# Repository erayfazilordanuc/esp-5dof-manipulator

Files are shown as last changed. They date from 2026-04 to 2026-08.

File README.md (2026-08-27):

# ESP32 5-DOF Manipulator

<p align="center">
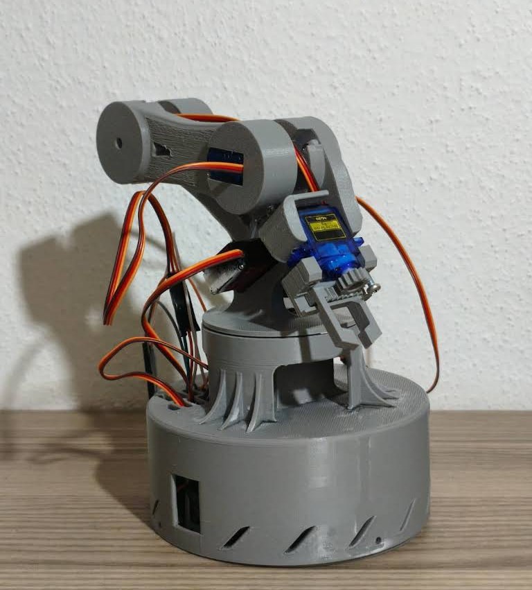
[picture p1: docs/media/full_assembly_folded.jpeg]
Arm in the folded pose
  
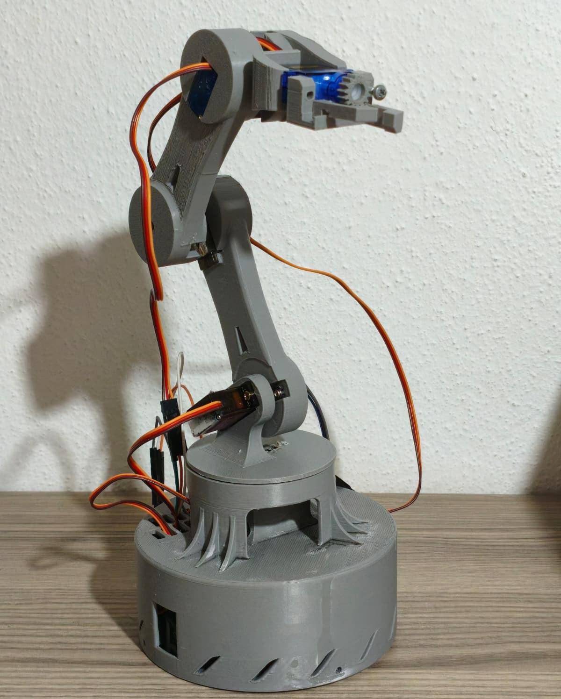
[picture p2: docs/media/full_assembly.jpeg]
Arm reaching forward
  
</p>

A five-axis robotic arm built from scratch: a 3D-printed structure, an ESP32 running the
motion controller, and a control page served straight off the board over Wi-Fi. No host
computer involved. The firmware is called ArmPilot.

The arm is driven by servos that report nothing back — no encoder, no current sense, no way
to ask one where it is. Three problems follow, and most of the design answers one of them:

- A servo that has just been powered up slams to whatever pulse width reaches it first, so
  firmware that attaches and writes an angle in the same breath makes the arm jump on boot.
- Software PWM on a chip that is also servicing Wi-Fi interrupts jitters — audible as
  buzzing, visible as twitching.
- Commanding a servo straight to its target makes it accelerate as hard as it can, which on
  a printed arm means wobble on departure and overshoot on arrival.

This is an open-loop system. The firmware controls what it *commands*; whether a link ended
up where it was told is not something the board can observe.

## Mechanics

<p align="center">
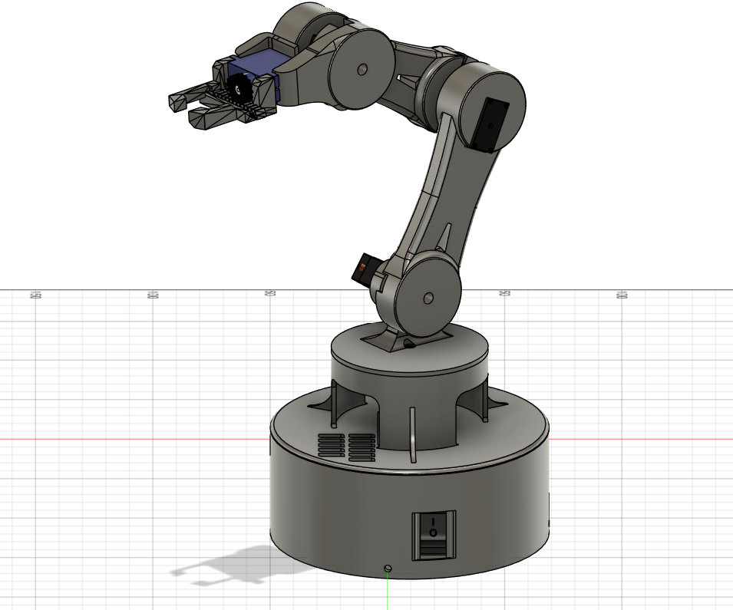
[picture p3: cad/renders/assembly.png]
CAD assembly
  
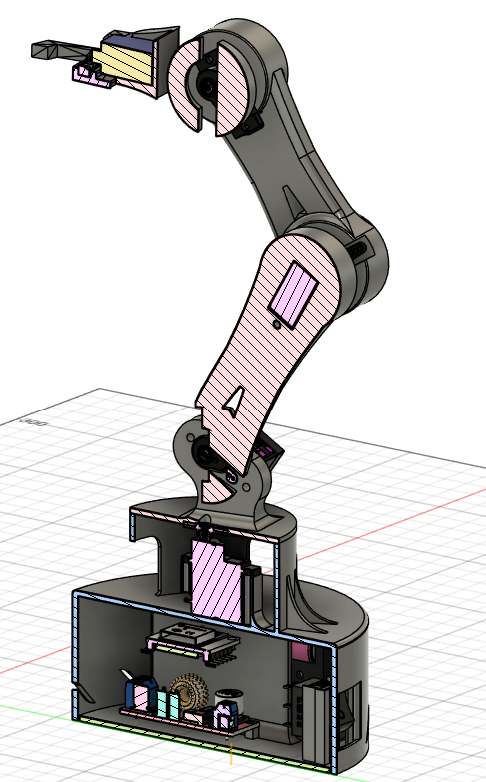
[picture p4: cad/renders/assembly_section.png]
Section view
  
</p>

Structural parts are printed in PETG rather than PLA, for less flex under load and better
tolerance of the heat that builds up around servos in a sealed base. The section view was the
working drawing for servo clearance, cable routing and wall thickness. The base is a closed
cylinder holding the electronics and battery, keeping the heaviest parts at the bottom and
the arm planted when the elbow is fully extended.

STLs are in [`cad/print_files/`](cad/print_files/), Fusion 360 sources in
[`cad/source/`](cad/source/). The browser draws the arm from link lengths the board sends on
connect, so changing the mechanics means editing one struct: base radius 62 mm, floor to
shoulder 105 mm, shoulder to elbow 110 mm, elbow to wrist 95 mm, wrist to tip 72 mm.

## Electronics

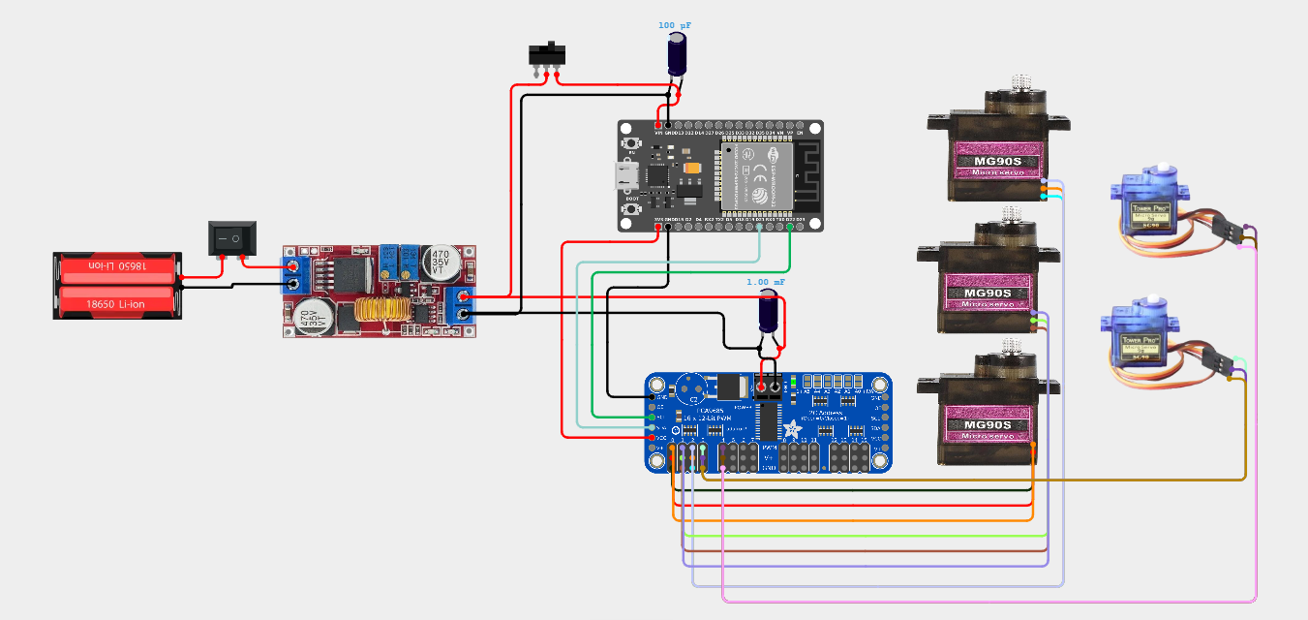
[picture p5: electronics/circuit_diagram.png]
Circuit diagram


All five PWM channels come from a PCA9685 at I²C `0x40` rather than the ESP32 itself. It
generates the pulses in hardware at 50 Hz while the ESP32 only writes a pulse width over the
bus at 400 kHz, so whatever the CPU is busy with never reaches the servo signal.

Two 18650 cells in series feed a single XL4015 buck converter, which supplies the ESP32 and
the servo rail in parallel — 100 µF on the logic side, 1000 µF across the servo rail. It is
still one rail, so a hard stall can drag the logic down with it. Splitting them is the next
revision: [`circuit_diagram_v2.png`](electronics/circuit_diagram_v2.png) gives the servos a
dedicated 8 A XL4016E1, and
[`circuit_diagram_v2_with_bms.png`](electronics/circuit_diagram_v2_with_bms.png) adds a 2S BMS
and USB-C charging.

| Qty | Part | Notes |
|---|---|---|
| 1 | ESP32-WROOM-32 devkit, 30-pin | Wi-Fi and two cores |
| 1 | Adafruit PCA9685 | 16-channel 12-bit PWM, I²C `0x40` |
| 3 | MG90S servo | Base, shoulder, elbow |
| 2 | SG90 servo | Wrist and gripper |
| 1 | XL4015 buck converter | Shared 5 V rail |
| 2 | 18650 Li-ion and holder | In series, about 7.4 V nominal |
| 1 each | 100 µF / 1000 µF electrolytic | Logic side / servo rail |
| 2 | Rocker / slide switch | Master and logic cut-off |

`GPIO21`/`GPIO22` carry I²C, `3V3` feeds the PCA9685 logic, grounds are common. Any 50 Hz
servo works in place of these; trim each axis with `usMin`/`usMax` in the joint table.

<p align="center">
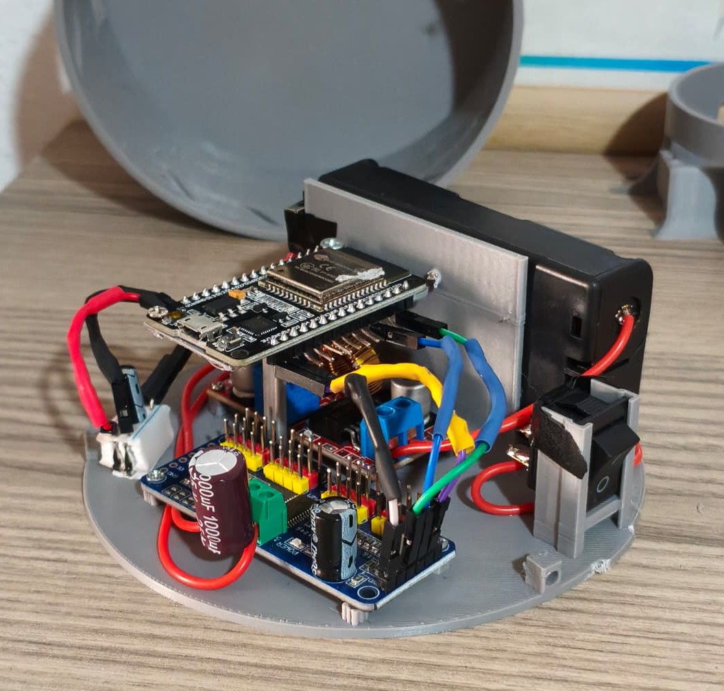
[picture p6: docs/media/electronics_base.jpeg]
Electronics stack in the base
  
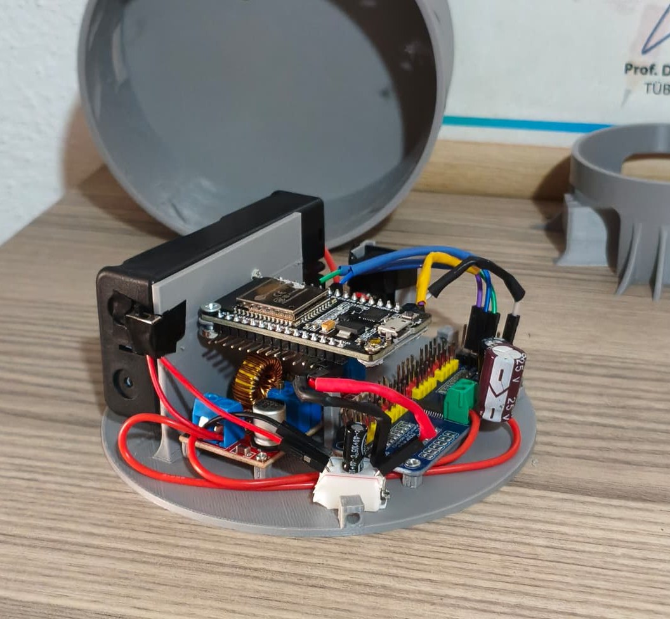
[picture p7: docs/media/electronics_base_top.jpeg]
Top view of the base
  
</p>

## Motion control

Without position feedback a PID loop has nothing to close around, so instead of correcting
error after the fact ArmPilot never commands a move the arm cannot follow. Every axis owns a
profile generator ([`motion_axis.h`](firmware/include/motion_axis.h)) stepped at 100 Hz,
handing the servo an intermediate setpoint every 10 ms under velocity, acceleration and jerk
limits.

```
velocity
   ^      ______________
   |     /              \     jerk limit smooths the take-off
   |    /                \    v = sqrt(2*a*distance) brake curve
   +---/------------------\--> time
```

The asymmetry is the point: jerk is limited only while accelerating, while braking keeps full
acceleration authority. Velocity is capped at `sqrt(2*a*distance)` from the target, so the
commanded setpoint arrives and stops rather than sailing past — a property of the generator,
not a correction applied afterwards. What the physical link then does is unobservable, and
none of this compensates for disturbance or a stalled servo.

Profile stepping runs in its own FreeRTOS task, pinned to core 1 at priority 3 with a fixed
period. Telemetry and WebSocket work happen in the lower-priority Arduino loop, so a busy
network is what gets preempted — the control step runs on time and the web work waits.

**[docs/motion-control.md](docs/motion-control.md)** — per-axis limits, profile output for a
90° move, the `s`/`s²`/`s³` speed-scaling law, task layout.

## The control page

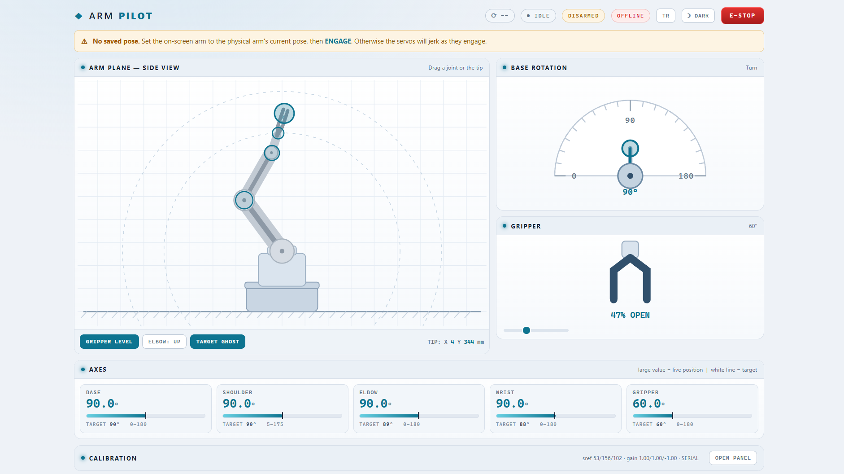
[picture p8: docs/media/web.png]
ArmPilot control page


The UI is a single page held in flash as `PROGMEM`, so there is no filesystem image to build
or upload. It gives two 2D views instead of five sliders, because sliders make you think in
servo angles and the shape of the robot is what you care about: a side view where dragging
the end point solves shoulder and elbow together through inverse kinematics, and a top view
dial for base rotation.

The solid arm is the setpoint the profile generator is commanding, streamed at 20 Hz; the
dashed ghost is the target it is working toward, fading as the two converge. Both come from
the firmware's model rather than from the arm itself, so the gap between them is how much of
the commanded move is still outstanding, not a tracking error. `Space` is emergency stop and
resume, `H` is home, `P` is park. English and Turkish come from one dictionary and the theme
follows the OS until overridden; both choices stay in `localStorage`, which is why the boot
reason arrives from the board as a code (`BROWNOUT`, `PANIC`, …) and is put into words in the
browser.

**Calibration** lives in the same page. Splined horns mount at whatever tooth lines up during
assembly, so each joint carries a linear map — `joint = wRef + gain * (servo - sRef)` —
instead of an assumed zero, and the sign of `gain` carries direction, so the reversed wrist
mount is just −1. Two unknowns need two samples: engage, pose the arm, drag the on-screen arm
to match, save two clearly different poses. The firmware fits and stores them, and rejects
fits it cannot trust, because a bad fit turns into motion. See
**[docs/calibration.md](docs/calibration.md)**.

Commands go over a WebSocket at `/ws` as plain text:

```
a <a0> <a1> <a2> <a3> <a4>   set all axes
j <id> <deg>                 set one axis
s <scale>                    speed scale, 0.15 to 1.30
c engage|release|home|park|stop|resume|save
k ...                        calibration: sample, solve, flip direction, reset
```

The board answers with a `hello` frame (geometry, joint limits, IP, last reset code), a `cal`
frame whenever calibration changes, and a 20 Hz state packet.

## Starting up without the jump

At boot ArmPilot emits no pulses at all: `ArmController::begin()` puts every PCA9685 channel
into full-off, so the servos stay torque-free and the arm cannot move until asked.

Two seconds after motion settles the joint angles go to NVS. On the next boot they are read
back as the assumed pose, and pressing engage writes that *stored* angle to each channel in
turn, 220 ms apart: the commanded angle already matches the physical one so nothing moves,
and staggering keeps the inrush from pulling the supply down. With no stored pose — or if the
arm was moved by hand while off — the page says so and asks you to match the on-screen arm to
the real one first.

What this cannot fix: if the ESP32 resets, outputs shut off and the arm drops under its own
weight. The servos have no brake. Wiring `/OE` to a GPIO lets the firmware kill outputs in
hardware too, but it does not hold the arm up.

## Build and flash

You need [PlatformIO](https://platformio.org/); dependencies resolve from `platformio.ini`.

```bash
git clone https://github.com/erayfazilordanuc/esp-5dof-manipulator.git
cd esp-5dof-manipulator/firmware

# Wi-Fi credentials are not kept in version control
cp include/secrets_example.h include/secrets.h   # then fill in SSID and password

pio run              # build
pio run -t upload    # flash
pio device monitor   # the IP address is printed here
```

If the network is unreachable the board brings up its own access point, `ArmPilot-AP` /
`armpilot1`, at `http://192.168.4.1`; on your own network `http://armpilot.local` works over
mDNS. The servos come up free by design — press engage in the UI to energise them.

`python tools/preview.py` extracts the embedded page and serves it on `localhost`, so UI work
does not need a flash cycle. Tuning is split between `firmware/include/config.h` (AP fallback,
I²C pins, control rate, boot behaviour) and `firmware/src/config.cpp` (joint table, link
geometry, calibration defaults); both are pushed to the browser on connect.

## When the servos go limp

Almost always the ESP32 has reset: outputs shut off, torque disappears, the arm sags. The
cause is captured on boot and reported as `BROWNOUT`, `PANIC` or `WATCHDOG`, and the page
also watches uptime — if it runs backwards while you are connected, the board restarted under
you and the badge says so. Brownout is the usual answer on a shared rail: give the servos
their own 5–6 V supply, tie the grounds together, keep 1000 µF across the rail.
`ENGAGE_STAGGER_MS` spreads out the start-up current, but peak current during a move is a
question of what the supply can deliver.

## Repository layout

```
cad/          print_files/ (STLs + v1 archive), renders/, source/ (Fusion 360)
docs/         motion-control.md, calibration.md, media/
electronics/  Circuit diagrams, plus legacy/ for the v1 schematic
firmware/     include/, src/, tools/preview.py, legacy/ (excluded from the build)
```

## What's next

Closing the loop is the gap worth naming: an IMU on the forearm, or angles pulled from
high-frame-rate video, would make the pose the arm actually reaches measurable and turn the
profile numbers from commanded into observed. Past that, this firmware is meant to become the
low-level hardware interface for an autonomous setup — micro-ROS bridging the board to a host,
a URDF model to simulate against, and MoveIt 2 planning off-board.

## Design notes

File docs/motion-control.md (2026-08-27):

# Motion control

Detail behind the [motion control section](../README.md#motion-control) of the main README.
Implementation: [`motion_axis.h`](../firmware/include/motion_axis.h), limits in
[`config.cpp`](../firmware/src/config.cpp).

## Why a profile generator and not a PID

A PID loop needs a measurement to subtract from the setpoint. The servos give none, so
there is nothing to close a loop around. The alternative is to make the reference itself
followable: shape every command into a curve that stays inside limits the mechanism is known
to handle, and hand the servo an intermediate setpoint every 10 ms rather than a distant
target.

This is not equivalent to feedback control. It removes the failure modes that come from
commanding steps into an inertial system, and it does nothing about disturbance, load or a
servo that stalls. Those stay invisible to the firmware.

## The curve

```
velocity
   ^      ______________
   |     /              \     jerk limit smooths the take-off
   |    /                \    v = sqrt(2*a*distance) brake curve
   +---/------------------\--> time
```

Each 10 ms step, per axis:

1. Compute the highest velocity from which the axis could still stop within the remaining
   distance: `vBrake = sqrt(2 * aMax * |error|)`.
2. Command `min(vMax, vBrake)`, signed toward the target.
3. Take the acceleration that reaches it, clamped to `±aMax`.
4. Rate-limit that acceleration by `jMax * dt` **only while speeding up**. While braking,
   full acceleration authority is available immediately.
5. Integrate.

Step 4 is the asymmetry that matters. Jerk limiting on departure is what stops a printed arm
wobbling as it leaves; jerk limiting on arrival would delay the brake and let the axis run
long. Because velocity is capped by the brake curve at every step, the commanded position
converges on the target instead of passing it — a property of the generator, not a
correction applied afterwards.

Retargeting mid-move keeps the current velocity and re-solves from there, so a new command
during motion blends rather than restarting from zero.

## Profile output for a 90° move

At the default 0.85x speed scale:

| Axis | Duration | Peak velocity | Travelled in first 100 ms |
|---|---|---|---|
| Base | 3.52 s | 34 °/s | 2 % |
| Shoulder | 4.39 s | 25 °/s | 2 % |
| Elbow | 2.27 s | 60 °/s | 3 % |
| Wrist | 1.82 s | 81 °/s | 4 % |
| Gripper | 1.41 s | 111 °/s | 5 % |

These describe the setpoint stream the servos are handed, not the motion of the physical
link. With nothing reporting back from the arm, only the first is observable. The small
figures in the last column are the jerk limit working: the axis eases off the mark rather
than snapping.

## Per-axis limits

| Axis | Channel | Range | Home | Park | v max | a max | jerk max |
|---|---|---|---|---|---|---|---|
| Base | 0 | 0–180° | 90° | 90° | 40 °/s | 55 °/s² | 300 °/s³ |
| Shoulder | 1 | 5–175° | 90° | 125° | 30 °/s | 42 °/s² | 220 °/s³ |
| Elbow | 2 | 0–180° | 90° | 155° | 70 °/s | 110 °/s² | 700 °/s³ |
| Wrist | 3 | 0–180° | 90° | 120° | 95 °/s | 160 °/s² | 1000 °/s³ |
| Gripper | 4 | 0–180° | 60° | 60° | 130 °/s | 260 °/s² | 1800 °/s³ |

Base and shoulder are slowest on purpose: they carry the most inertia and the most load.

## Speed scaling

The UI slider spans 0.15x to 1.30x and scales the whole set together:

```
vMax * s        aMax * s²       jMax * s³
```

Those exponents keep the shape of the curve invariant — a slow move is the same move
stretched in time, not a differently shaped one. Scaling only velocity would produce a move
that still departs abruptly and merely crawls in the middle.

## Task structure

Profile generation runs in its own FreeRTOS task, created with:

```c
xTaskCreatePinnedToCore(motionTask, "motion", 6144, nullptr, 3, nullptr, 1);
```

Priority 3 puts it above the Arduino `loopTask` (priority 1), which is where telemetry
broadcast and WebSocket housekeeping live. So when the network is busy, the scheduler
preempts the web work and runs the control step on time — not the other way round. A control
loop whose period depends on network load is not a control loop.

Two things make the timing forgiving beyond that. The task sleeps to a fixed period rather
than a fixed delay, so its own work does not accumulate drift. And servo pulses come from the
PCA9685, which keeps emitting clean 50 Hz output on its own — a late task writes a slightly
stale pulse width, it does not produce a malformed pulse.

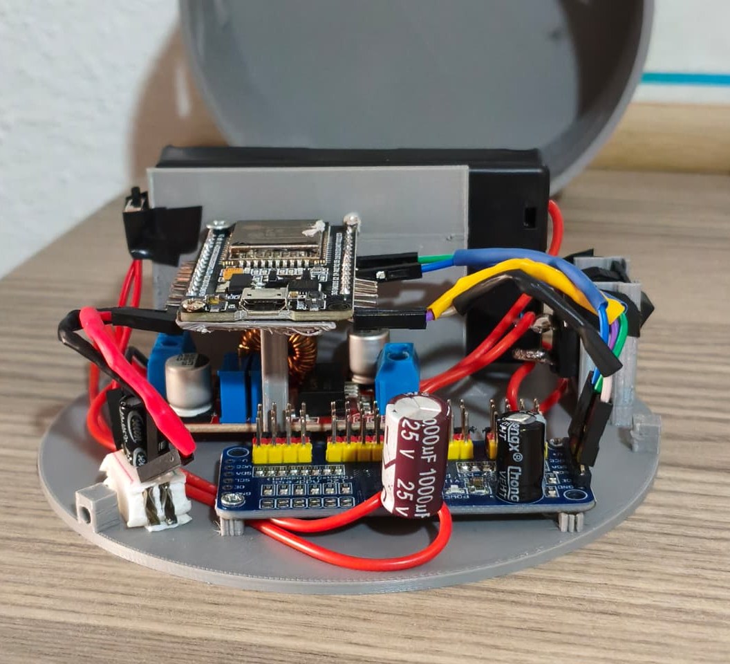
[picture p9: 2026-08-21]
docs/media/electronics_base_front.jpeg

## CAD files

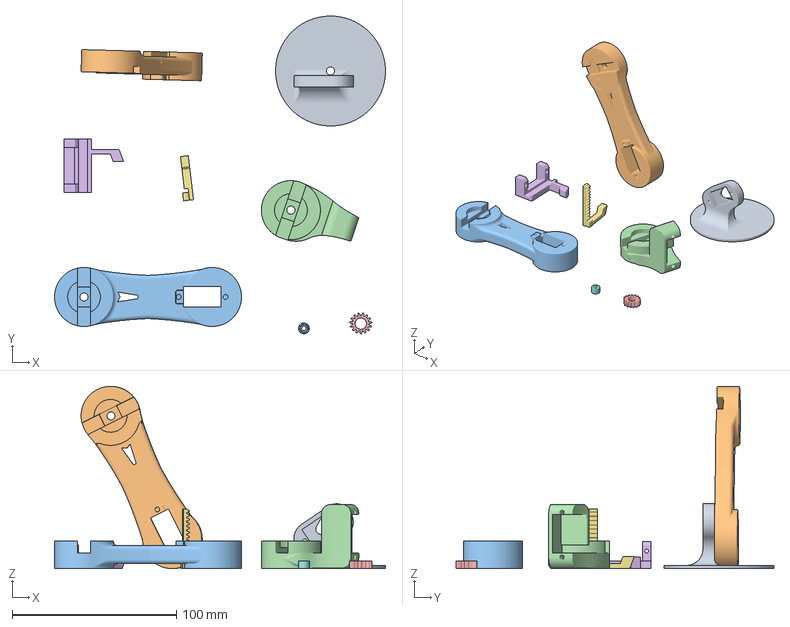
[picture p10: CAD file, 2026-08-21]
cad/print_files/after the base prints.3mf
201.7 x 193.8 x 111.1 mm
J1 Lid.stl
J2 Arm.stl
J3 Arm.stl
J4 wHousing.stl
Gripper Round Gear.stl
Gripper Mount.stl
Gripper Gear and Finger.stl
Servo Shoulder Center.stl

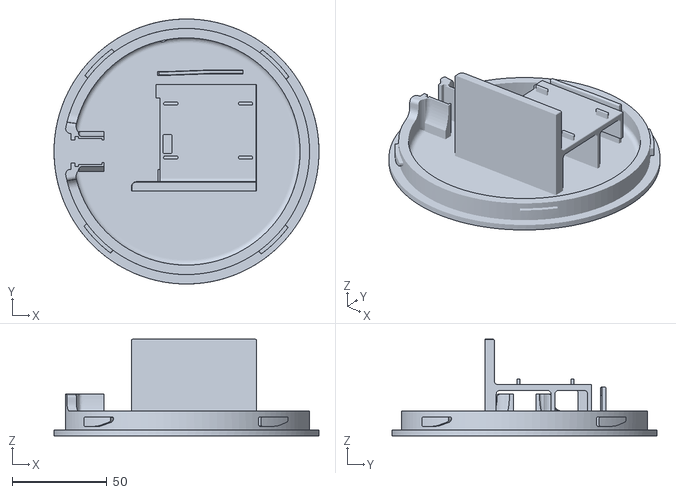
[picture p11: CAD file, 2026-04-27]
cad/print_files/v1/Base Housing.stl
140.0 x 140.0 x 51.0

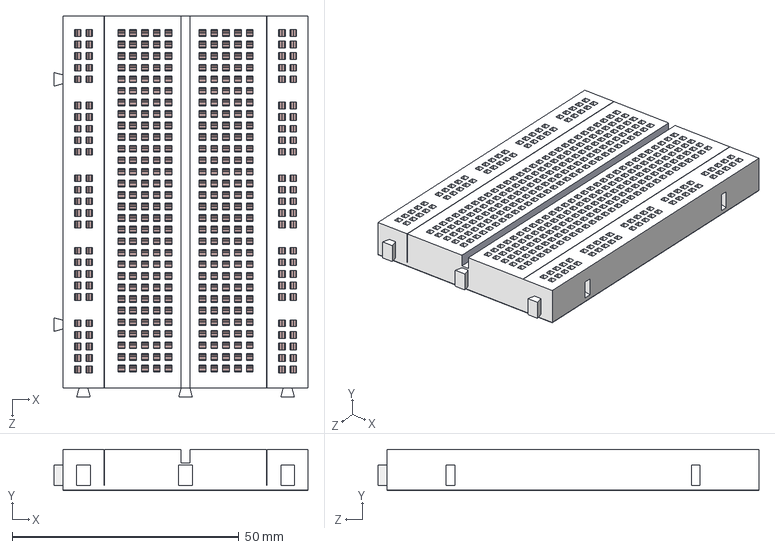
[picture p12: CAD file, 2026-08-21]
cad/source/Imports/8-5-x-5-5-1.snapshot.1/Макетная плата 8,5 x 5,5 см/Макетная плата 8,5 x 5,5 см.STEP
56.0 x 9.10 x 84.0 mm

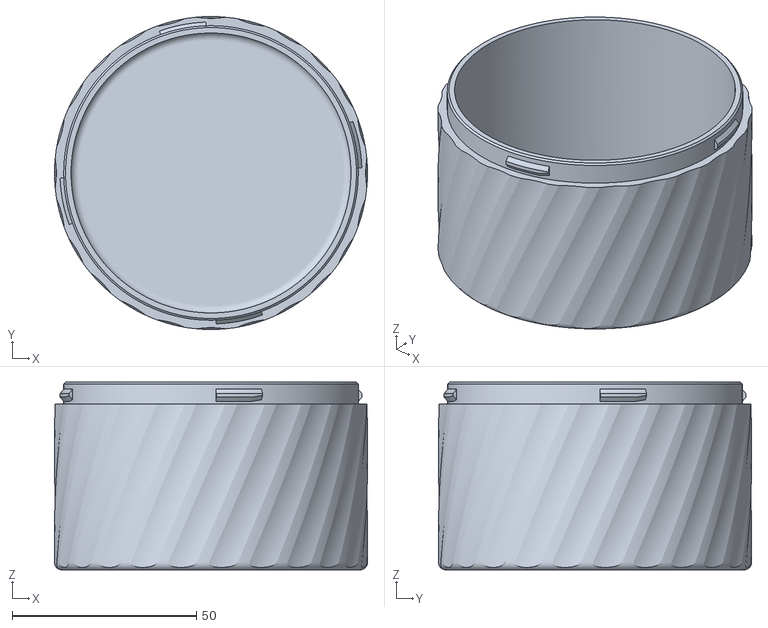
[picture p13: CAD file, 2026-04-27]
cad/source/Imports/Bayonet Mount Sample/container.stl
85.0 x 85.0 x 51.0

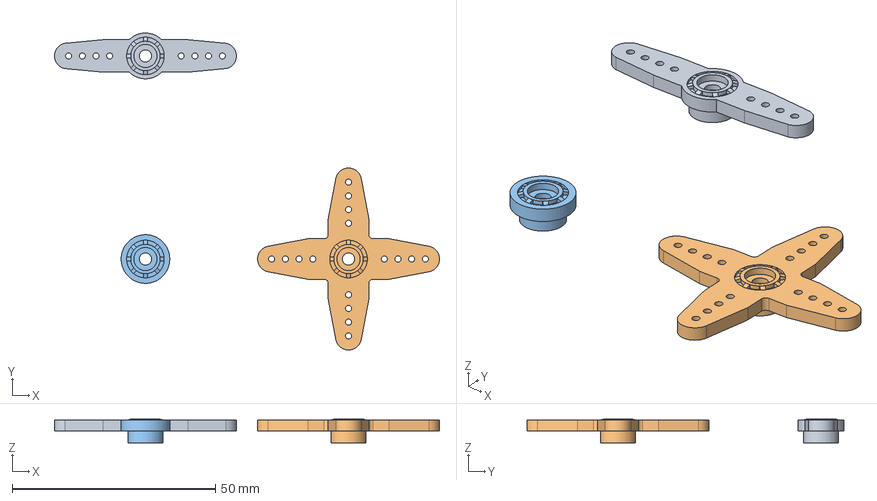
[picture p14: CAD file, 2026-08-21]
cad/source/Imports/mg996r-servo-3.snapshot.9/mg996_arms.FCStd
94.8 x 78.0 x 5.90 mm
Corps
Corps001
Corps002

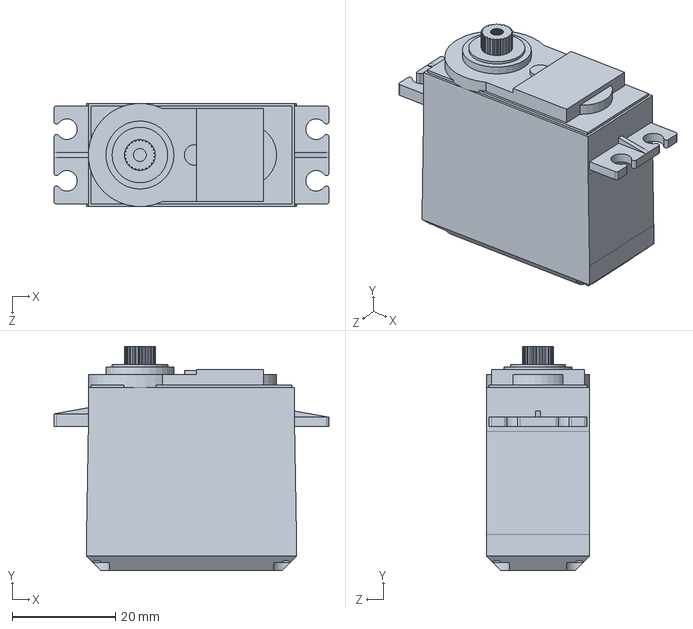
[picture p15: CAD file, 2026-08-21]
cad/source/Imports/mg996r-servo-motor-4.snapshot.6/MG996R_servo.SLDPRT
53.3 x 43.5 x 20.0 mm

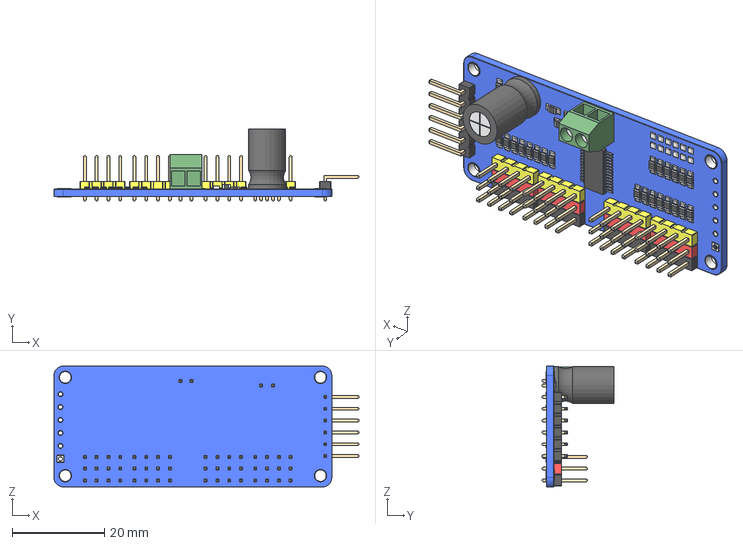
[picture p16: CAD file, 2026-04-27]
cad/source/Imports/pca9685-pwm-servo-driver-for-arduino-1.snapshot.1/PCA9685 v18.step
66.1 x 15.6 x 26.2 mm

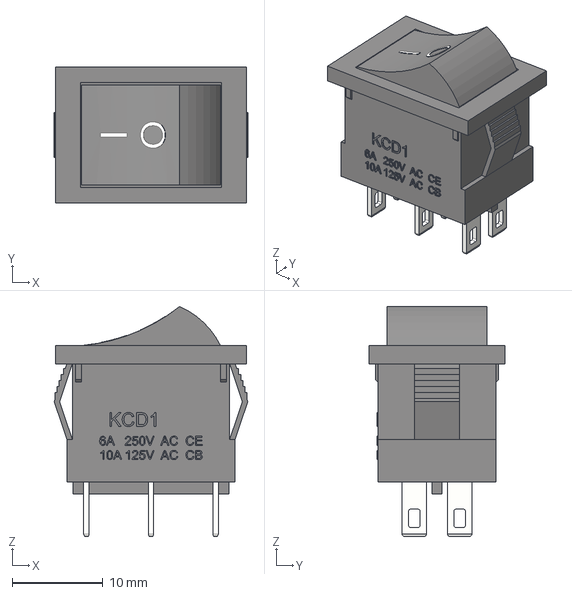
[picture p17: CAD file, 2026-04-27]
cad/source/Imports/rocker-switch-kcd-1-1.snapshot.3/Rocker Switch 11.step
21.3 x 15.0 x 25.3 mm

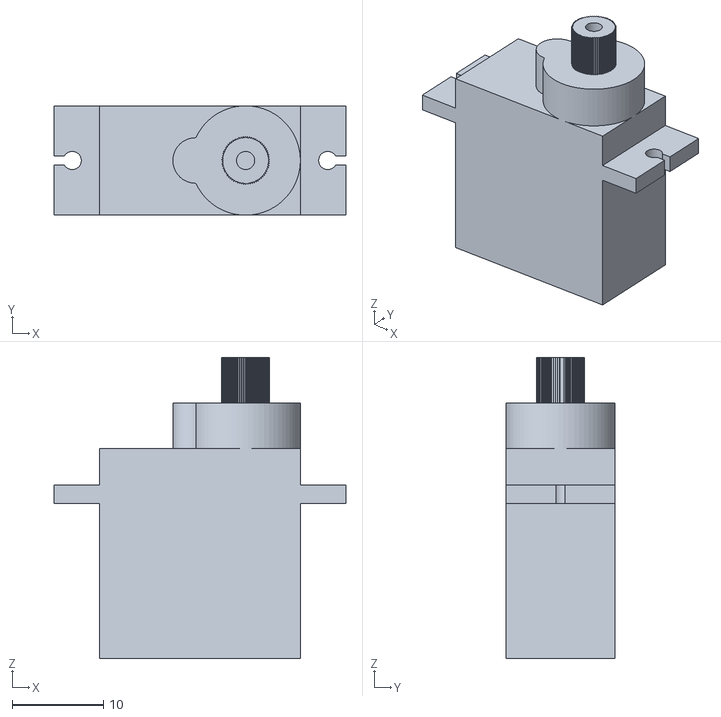
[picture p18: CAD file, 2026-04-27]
cad/source/Imports/servo-motor-mg90s-2.snapshot.1/sero motor/servo motor (mg90s) .stl
32.0 x 12.0 x 33.0

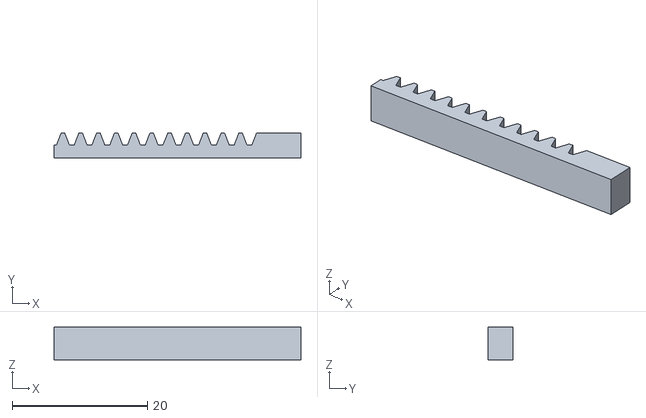
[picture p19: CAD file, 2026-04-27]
cad/source/Imports/Simple 3d printed 9g servo gripper - 2302957/files/Linear_gear.stl
36.5 x 3.68 x 4.84

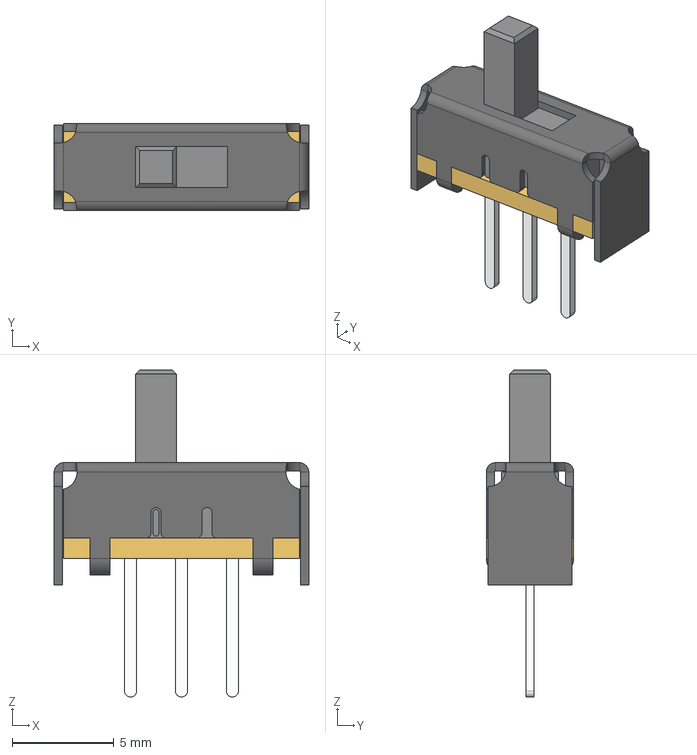
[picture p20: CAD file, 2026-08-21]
cad/source/Imports/slide-switch-slw-116641-3a-ra-s-d-1.snapshot.3/SLW-116641-3A-RA-S-D.step
12.5 x 4.29 x 16.1 mm

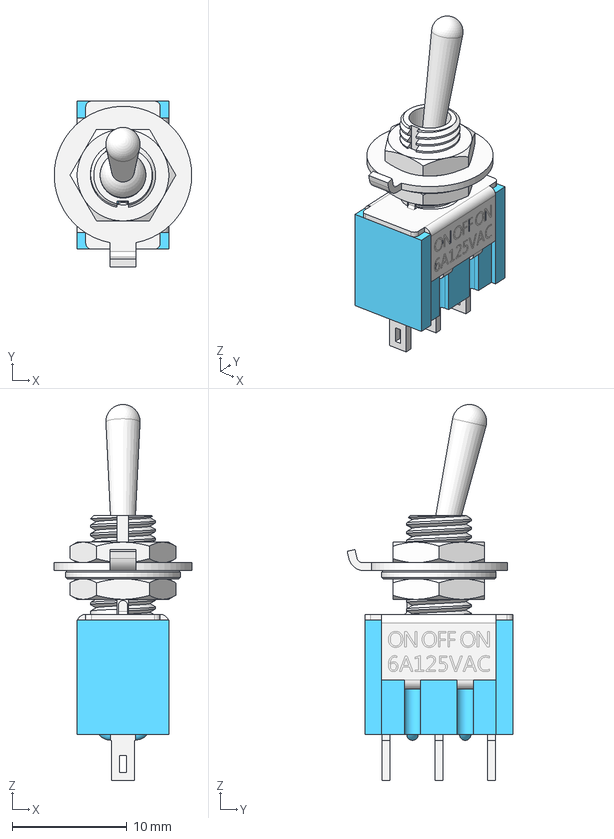
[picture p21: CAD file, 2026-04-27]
cad/source/Imports/toggle-switch-29.snapshot.4/ToggleSwitch 3Pin.step
12.0 x 14.4 x 32.8 mm
Washer Anti Twist Protection
Nut M6x0.75mm
Nut M6x0.75mm clone
Sheetmatal Frame
Plastic Body
Thread
Batton Clone 1
PIN_1of3
PIN_2of3
PIN_3of3
Washer

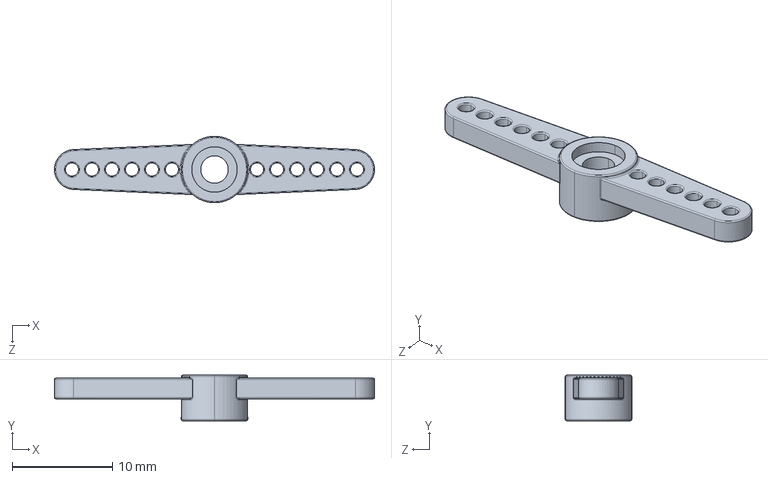
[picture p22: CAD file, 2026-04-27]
cad/source/Imports/tower-pro-mg90s-micro-servo-2.snapshot.3/Bidirectional shoulder.STEP
32.0 x 4.55 x 6.65 mm

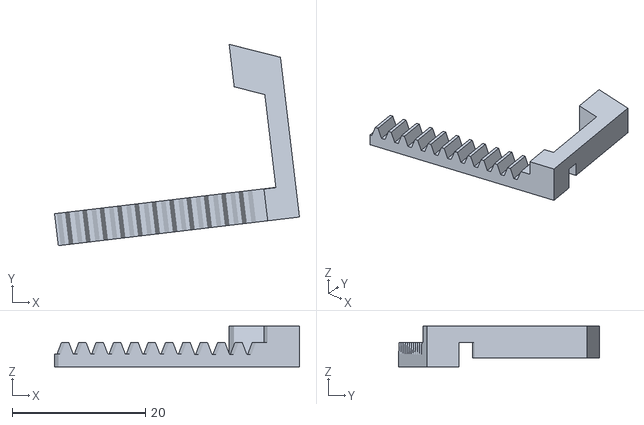
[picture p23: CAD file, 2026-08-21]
cad/print_files/Gripper Gear and Finger.stl
36.8 x 30.2 x 6.14

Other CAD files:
cad/print_files/v1/Axis 1 Servo Cover.stl
cad/source/Imports/Bayonet Mount Sample/lid.stl
cad/source/Imports/mg996r-servo-3.snapshot.9/mg996_arm_2pad.step
cad/source/Imports/servo-motor-mg90s-2.snapshot.1/sero motor/servo motor (mg90s) v1.step
cad/print_files/Base Housing.stl
cad/print_files/Base Lid.stl
cad/print_files/Gripper Mount.stl
cad/print_files/Gripper Round Gear.stl
cad/print_files/J1 Lid.stl
cad/print_files/J2 Arm.stl
cad/print_files/J3 Arm.stl
cad/print_files/J4 wHousing.stl
cad/print_files/Servo Shoulder Center.stl
cad/print_files/v1/Axis 1 Lid.stl
cad/print_files/v1/Axis 2.stl
cad/print_files/v1/Axis 4.stl
cad/print_files/v1/Base Lid Lower.stl
cad/print_files/v1/Base Lid Upper.stl
cad/print_files/v1/Base Lid.stl
cad/print_files/v1/Base Lids Print Preview.3mf
cad/source/Assembly.f3z
cad/source/Axis 1 Lid.f3z
cad/source/Axis 1 Servo Cover.f3d
cad/source/Axis 2.f3d
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

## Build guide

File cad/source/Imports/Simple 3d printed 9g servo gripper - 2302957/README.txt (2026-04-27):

Simple 3d printed 9g servo gripper by brunoip on Thingiverse: https://www.thingiverse.com/thing:2302957

Summary:
A simple 3d printed claw that I designed to be used with a 9g servo. It keeps the servo parallel to te claw action in order to reduce the weight in the arm.https://www.youtube.com/watch?v=FNFmIbqV8nc

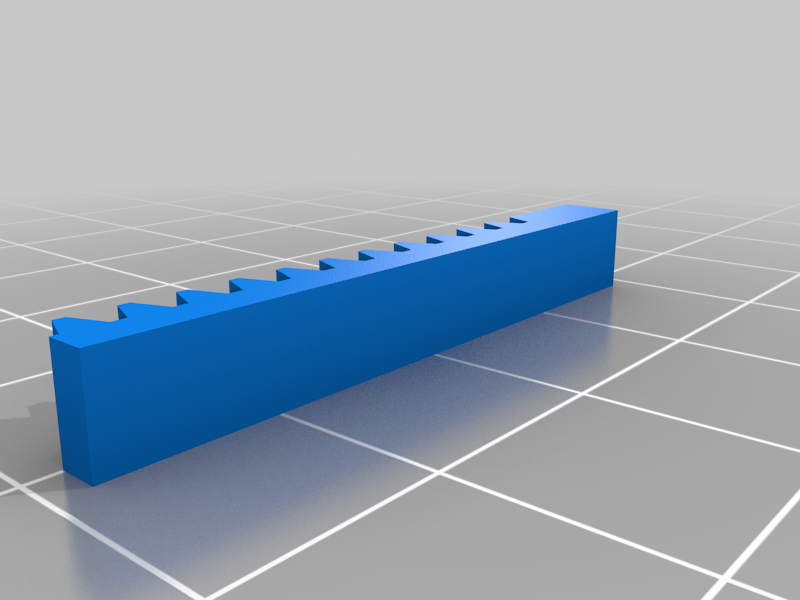
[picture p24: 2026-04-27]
cad/source/Imports/Simple 3d printed 9g servo gripper - 2302957/images/4447406b796346cbbac16ed00bb02373.png

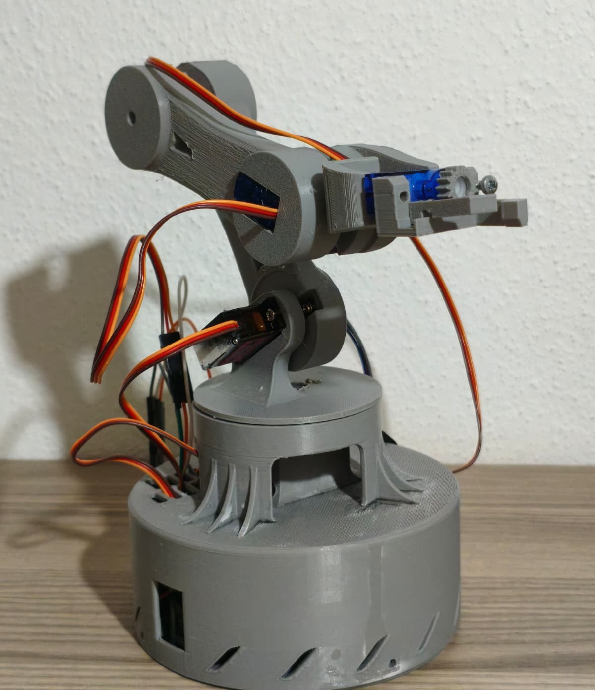
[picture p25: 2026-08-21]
docs/media/full_assembly_side.jpeg

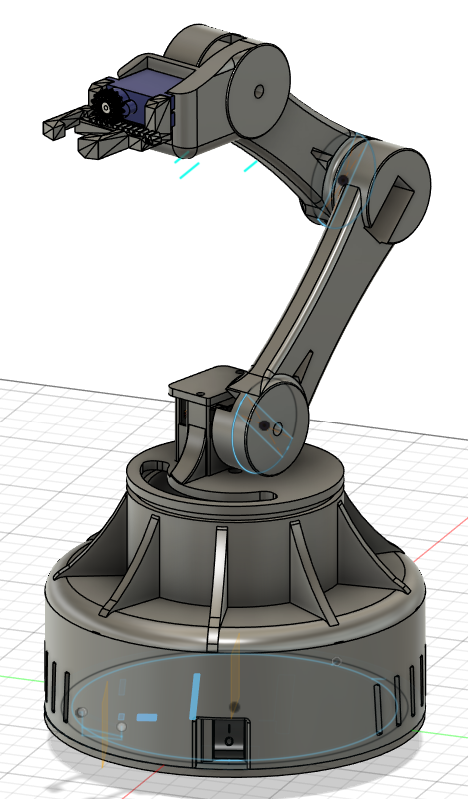
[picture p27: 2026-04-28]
cad/renders/assembly_v1.png

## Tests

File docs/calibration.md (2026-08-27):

# Calibration

Detail behind the calibration paragraph in the [main README](../README.md#the-control-page).
Constants live in [`config.h`](../firmware/include/config.h), the solver in
[`arm_controller.cpp`](../firmware/src/arm_controller.cpp).

## The problem

Servo horns are splined, so a horn mounts at whatever tooth lines up during assembly. "Servo
0° means the link points straight up" is never true out of the box, and where a joint is
geared, one degree of servo is not one degree of link. Hard-coding an offset means
re-flashing after every disassembly.

## The model

Each of the three arm joints carries a linear map instead of an assumption:

```
joint_angle = wRef + gain * (servo_angle - sRef)
```

- `sRef` / `wRef` — a matched pair: servo angle and real joint angle at one known pose.
- `gain` — joint degrees per servo degree. Its **sign** encodes direction, so a mirrored
  mount solves to a negative value with no code change. Its **magnitude** carries the
  reduction ratio; direct drive gives ±1.

Two unknowns per joint, so two samples are needed. The defaults shipped in
[`config.cpp`](../firmware/src/config.cpp) were measured with the arm held straight up, where
the shoulder's world angle is 90° and elbow and wrist are 0° relative to the previous link:

| Joint | `sRef` | `wRef` | `gain` |
|---|---|---|---|
| Shoulder | 53.4° | 90.0° | +1.0 |
| Elbow | 156.4° | 0.0° | +1.0 |
| Wrist | 101.5° | 0.0° | −1.0 (mounted reversed) |

The wrist is the case the sign exists for: the servo is installed facing the other way, and
that costs one character in a table rather than a branch in the code.

## The procedure

1. Engage the arm, so the servos hold torque and their commanded angle is meaningful.
2. Move the real arm to a clear pose using the panel sliders.
3. Drag the on-screen arm until its shape matches what you see, and save as sample 0.
4. Move to a second, clearly different pose and save as sample 1.
5. Solve. The firmware fits `gain` and the reference pair per joint and writes them to NVS.

Gripper open/close references and the serial/parallel kinematic mode are captured separately
from the same panel.

## Guardrails

The solver rejects more than it accepts, because a bad fit is worse than no fit — it turns
into motion.

| Check | Threshold | Reason |
|---|---|---|
| Sample span | `CAL_MIN_SPAN_DEG` = 8° | Two samples from nearly the same pose carry no information; that axis is skipped and keeps its previous value rather than being fitted from noise. |
| Arm state | Must be engaged and stopped | With no torque the servo is wherever gravity left it, so the recorded servo angle means nothing. Mid-move samples pair a stale angle with a settled drawing. |
| Gain range | `CAL_GAIN_MIN` 0.05 to `CAL_GAIN_MAX` 20 | Outside this, no plausible linkage explains the fit. In practice this catches swapped channels and mis-drawn poses before they become motion. |
| Numerics | `isfinite` on every solved value | A degenerate fit must not reach NVS. |

A rejected axis is reported back to the UI rather than failing silently, and the same range
check runs again when calibration is loaded from NVS at boot — so a corrupted store falls
back to defaults instead of driving the arm somewhere unexpected.

## WebSocket commands

All calibration goes over the same `/ws` text protocol as motion:

```
k p <0|1> <q0> <q1> <q2>   store a matching sample in slot 0 or 1
k f                        solve both samples and save
k x                        discard stored samples
k c                        take the current pose as the upright reference
k d <0..2>                 flip direction of shoulder / elbow / wrist
k m <0|1>                  kinematic mode: 0 serial, 1 parallel
k g o|c                    capture gripper fully-open / fully-closed reference
k r                        reset to factory defaults and save
```

Any change re-broadcasts a `cal` frame to every connected client, so a second browser tab
never shows stale calibration.

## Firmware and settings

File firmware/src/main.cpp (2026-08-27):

/**
 * =============================================================================
 *  ArmPilot - 5 eksen robot kol kontrolcusu
 *  Yazar : Eray Fazil Ordanuc
 *  Donanim: ESP32 + PCA9685 + 5x analog servo
 * =============================================================================
 *
 *  MIMARI
 *  ------
 *  Core 1 / oncelik 3 : "motion" gorevi -> 100 Hz sabit periyot, hareket
 *                       profillerini isler ve PCA9685'e yazar. WiFi trafigi
 *                       hareketin duzgunlugunu etkilemez.
 *  Core * / oncelik 1 : Arduino loop() -> telemetri yayini, baglanti bakimi.
 *  AsyncTCP gorevi    : WebSocket komutlari -> ArmController'a guvenli aktarim.
 *
 *  GUVENLI ACILIS
 *  --------------
 *  Acilista hicbir servo kanalina darbe gonderilmez (PCA9685 "full-off").
 *  Servolar torksuz kalir, yani kol acilista ASLA sicramaz. Kullanici arayuzden
 *  "ETKINLESTIR" dedigi anda, NVS'te saklanan son poz kanal kanal (araya
 *  gecikme koyarak) uygulanir. Yazilan aci fiziksel konumla ayni oldugu icin
 *  servo yerinden oynamaz; ayrica kanallar sirayla acildigi icin akim piki
 *  olusmaz ve besleme cokmez.
 */

#include <Arduino.h>
#include <WiFi.h>
#include <ESPmDNS.h>
#include <AsyncTCP.h>
#include <ESPAsyncWebServer.h>
#include <esp_system.h>

#include "config.h"
#include "arm_controller.h"
#include "web_ui.h"

static AsyncWebServer server(80);
static AsyncWebSocket ws("/ws");

// ===========================================================================
//  Reset teshisi
//  "Servolar durduk yere serbest kaliyor" sikayetinin en sik sebebi ESP32'nin
//  resetlenmesidir (servolar akim cekince besleme cokerse BROWNOUT). Reset
//  olunca PCA9685 cikislari kapanir ve kol torksuz kalir. Sebebi burada
//  yakalayip hem seri porta hem arayuze bildiriyoruz.
// ===========================================================================
static const char *resetReasonText()
{
    switch (esp_reset_reason())
    {
    case ESP_RST_POWERON:  return "GUC VERILDI";
    case ESP_RST_EXT:      return "HARICI RESET";
    case ESP_RST_SW:       return "YAZILIM RESET";
    case ESP_RST_PANIC:    return "PANIC (yazilim hatasi)";
    case ESP_RST_INT_WDT:  return "WATCHDOG (int)";
    case ESP_RST_TASK_WDT: return "WATCHDOG (gorev)";
    case ESP_RST_WDT:      return "WATCHDOG";
    case ESP_RST_BROWNOUT: return "BROWNOUT (besleme cokmesi!)";
    case ESP_RST_DEEPSLEEP:return "DERIN UYKU";
    case ESP_RST_SDIO:     return "SDIO";
    default:               return "BILINMIYOR";
    }
}
/* Arayuz iki dilli oldugu icin sebep JSON'a METIN degil KOD olarak girer;
   okunur karsiligini web_ui.cpp'deki sozluk secili dilde yazar. */
static const char *resetReasonCode()
{
    switch (esp_reset_reason())
    {
    case ESP_RST_POWERON:  return "POWERON";
    case ESP_RST_EXT:      return "EXT";
    case ESP_RST_SW:       return "SW";
    case ESP_RST_PANIC:    return "PANIC";
    case ESP_RST_INT_WDT:  return "INT_WDT";
    case ESP_RST_TASK_WDT: return "TASK_WDT";
    case ESP_RST_WDT:      return "WDT";
    case ESP_RST_BROWNOUT: return "BROWNOUT";
    case ESP_RST_DEEPSLEEP:return "DEEPSLEEP";
    case ESP_RST_SDIO:     return "SDIO";
    default:               return "UNKNOWN";
    }
}
static const char *g_resetReason = "UNKNOWN";

// ===========================================================================
//  Telemetri
// ===========================================================================
static String buildHello()
{
    float cur[NUM_JOINTS], tg[NUM_JOINTS];
    arm.snapshot(cur, tg);

    String s;
    s.reserve(900);
    s += F("{\"t\":\"hello\",\"cur\":[");
    for (uint8_t i = 0; i < NUM_JOINTS; i++)
    {
        if (i)
            s += ',';
        s += String(cur[i], 1);
    }
    s += F("],\"cfg\":{\"fw\":\"");
    s += F(FW_VERSION);
    s += F("\",\"host\":\"");
    s += F(MDNS_HOST ".local");
    s += F("\",\"ip\":\"");
    s += (WiFi.getMode() == WIFI_AP) ? WiFi.softAPIP().toString() : WiFi.localIP().toString();
    s += F("\",\"rst\":\"");
    s += g_resetReason;

    s += F("\",\"geo\":{\"baseR\":");
    s += String(GEOMETRY.baseRadius, 1);
    s += F(",\"baseH\":");
    s += String(GEOMETRY.baseHeight, 1);
    s += F(",\"l1\":");
    s += String(GEOMETRY.linkUpperArm, 1);
    s += F(",\"l2\":");
    s += String(GEOMETRY.linkForearm, 1);
    s += F(",\"l3\":");
    s += String(GEOMETRY.linkGripper, 1);

    s += F("},\"j\":[");
    for (uint8_t i = 0; i < NUM_JOINTS; i++)
    {
        if (i)
            s += ',';
        s += F("{\"n\":\"");
        s += JOINTS[i].name;
        s += F("\",\"lo\":");
        s += String(JOINTS[i].minDeg, 0);
        s += F(",\"hi\":");
        s += String(JOINTS[i].maxDeg, 0);
        s += '}';
    }
    s += F("]}}");
    return s;
}

/** Kalibrasyon paketi - baglantida ve her degisiklikte gonderilir. */
static String buildCal()
{
    const CalData &c = arm.cal();
    String s;
    s.reserve(260);
    s += F("{\"t\":\"cal\",\"sref\":[");
    s += String(c.sRef[0], 1) + ',' + String(c.sRef[1], 1) + ',' + String(c.sRef[2], 1);
    s += F("],\"wref\":[");
    s += String(c.wRef[0], 1) + ',' + String(c.wRef[1], 1) + ',' + String(c.wRef[2], 1);
    s += F("],\"gain\":[");
    s += String(c.gain[0], 4) + ',' + String(c.gain[1], 4) + ',' + String(c.gain[2], 4);
    s += F("],\"gr\":[");
    s += String(c.gripOpen, 1) + ',' + String(c.gripClose, 1);
    s += F("],\"par\":");
    s += String((int)c.parallel);
    s += F(",\"smp\":[");
    s += String(arm.calSampleValid(0) ? 1 : 0) + ',' + String(arm.calSampleValid(1) ? 1 : 0);
    // Kaydedilmis orneklerin servo acilari: arayuz "bu eksen yeterince oynadi
    // mi" geri bildirimini bunlardan uretir.
    for (uint8_t k = 0; k < 2; k++)
    {
        const CalSample &sm = arm.calSampleData(k);
        s += (k == 0) ? F("],\"s0\":[") : F("],\"s1\":[");
        s += String(sm.servo[0], 1) + ',' + String(sm.servo[1], 1) + ',' + String(sm.servo[2], 1);
    }
    s += F("],\"fit\":");
    s += String((int)arm.lastFitMask());
    s += '}';
    return s;
}

static size_t buildState(char *buf, size_t cap)
{
    float cur[NUM_JOINTS], tg[NUM_JOINTS];
    arm.snapshot(cur, tg);

    return snprintf(buf, cap,
                    "{\"t\":\"s\",\"s\":%u,\"m\":%u,\"k\":%u,\"v\":%.2f,\"up\":%lu,"
                    "\"c\":[%.1f,%.1f,%.1f,%.1f,%.1f],"
                    "\"g\":[%.1f,%.1f,%.1f,%.1f,%.1f]}",
                    (unsigned)arm.state(), arm.isMoving() ? 1u : 0u, arm.poseKnown() ? 1u : 0u,
                    arm.speedScale(), (unsigned long)(millis() / 1000UL),
                    cur[0], cur[1], cur[2], cur[3], cur[4],
                    tg[0], tg[1], tg[2], tg[3], tg[4]);
}

// ===========================================================================
//  Komut ayristirma
//    "a <a0> <a1> <a2> <a3> <a4>"  tum eksenler
//    "j <id> <aci>"                tek eksen
//    "s <olcek>"                   hiz olcegi (0.15 .. 1.30)
//    "c <komut>"                   engage|release|home|park|stop|resume|save
//    "k <alt-komut>"               kalibrasyon (bkz. asagi)
// ===========================================================================
static volatile bool g_calChanged = false;

static void handleCommand(char *msg)
{
    char *save = nullptr;
    const char *op = strtok_r(msg, " \t", &save);
    if (!op)
        return;

    switch (op[0])
    {
    case 'a':
    {
        float a[NUM_JOINTS];
        for (uint8_t i = 0; i < NUM_JOINTS; i++)
        {
            const char *tok = strtok_r(nullptr, " \t", &save);
            if (!tok)
                return; // eksik paket -> yok say
            a[i] = strtof(tok, nullptr);
        }
        arm.setAllTargets(a);
        break;
    }
    case 'j':
    {
        const char *sid = strtok_r(nullptr, " \t", &save);
        const char *sv = strtok_r(nullptr, " \t", &save);
        if (sid && sv)
            arm.setJointTarget((uint8_t)atoi(sid), strtof(sv, nullptr));
        break;
    }
    case 's':
    {
        const char *sv = strtok_r(nullptr, " \t", &save);
        if (sv)
            arm.setSpeedScale(strtof(sv, nullptr));
        break;
    }
    case 'c':
    {
        const char *c = strtok_r(nullptr, " \t\r\n", &save);
        if (!c)
            return;
        if (!strcmp(c, "engage"))
            arm.requestEngage();
        else if (!strcmp(c, "release"))
            arm.requestRelease();
        else if (!strcmp(c, "home"))
            arm.requestHome();
        else if (!strcmp(c, "park"))
            arm.requestPark();
        else if (!strcmp(c, "stop"))
            arm.requestStop();
        else if (!strcmp(c, "resume"))
            arm.requestResume();
        else if (!strcmp(c, "save"))
            arm.requestSave();
        break;
    }
    case 'k':
    {
        // k c                      -> mevcut pozu "dimdik yukari" referansi al
        // k d <0..2>               -> omuz/dirsek/bilek yonunu cevir
        // k m <0|1>                -> kinematik modu (0 seri, 1 paralel)
        // k g o|c                  -> kiskac tam acik / tam kapali referansi
        // k r                      -> fabrika ayarlarina don
        // k p <0|1> <q0> <q1> <q2> -> kalibrasyon modu: esleme ornegi kaydet
        // k f                      -> iki ornekten gain/referans coz ve kaydet
        // k x                      -> ornekleri sil
        const char *sub = strtok_r(nullptr, " \t\r\n", &save);
        if (!sub)
            return;
        const char *argp = strtok_r(nullptr, " \t\r\n", &save);

        switch (sub[0])
        {
        case 'c':
            arm.calCapture();
            break;
        case 'd':
            if (!argp)
                return;
            arm.calFlipDir((uint8_t)atoi(argp));
            break;
        case 'm':
            if (!argp)
                return;
            arm.calSetParallel(atoi(argp) != 0);
            break;
        case 'g':
            if (!argp)
                return;
            arm.calSetGripper(argp[0] == 'o');
            break;
        case 'r':
            arm.calReset();
            arm.calSave();
            break;
        case 'p':
        {
            if (!argp)
                return;
            float q[3];
            for (uint8_t i = 0; i < 3; i++)
            {
                const char *tok = strtok_r(nullptr, " \t\r\n", &save);
                if (!tok)
                    return; // eksik paket -> yok say
                q[i] = strtof(tok, nullptr);
            }
            arm.calSample((uint8_t)atoi(argp), q);
            break;
        }
        case 'f':
            arm.calFit();
            break;
        case 'x':
            arm.calClearSamples();
            break;
        default:
            return;
        }

        g_calChanged = true;
        break;
    }
    default:
        break;
    }
}

static void onWsEvent(AsyncWebSocket *, AsyncWebSocketClient *client,
                      AwsEventType type, void *arg, uint8_t *data, size_t len)
{
    if (type == WS_EVT_CONNECT)
    {
        Serial.printf("[WS] istemci #%u baglandi\n", client->id());
        client->text(buildHello());
        client->text(buildCal());
    }
    else if (type == WS_EVT_DISCONNECT)
    {
        Serial.printf("[WS] istemci #%u ayrildi\n", client->id());
    }
    else if (type == WS_EVT_DATA)
    {
        AwsFrameInfo *info = (AwsFrameInfo *)arg;
        if (!(info->final && info->index == 0 && info->len == len && info->opcode == WS_TEXT))
            return;
        if (len == 0 || len > 127)
            return;

        char buf[128];
        memcpy(buf, data, len);
        buf[len] = '\0';
        handleCommand(buf);
    }
}

// ===========================================================================
//  Hareket gorevi - sabit periyot, WiFi'den bagimsiz
// ===========================================================================
static void motionTask(void *)
{
    const TickType_t period = pdMS_TO_TICKS(1000 / CTRL_HZ);
    const float dt = 1.0f / (float)CTRL_HZ;
    TickType_t last = xTaskGetTickCount();

    for (;;)
    {
        arm.tick(dt);
        vTaskDelayUntil(&last, period);
    }
}

// ===========================================================================
//  Ag
// ===========================================================================
static void startNetwork()
{
    WiFi.mode(WIFI_STA);
    WiFi.setSleep(false); // dusuk gecikmeli WebSocket icin
    WiFi.begin(WIFI_SSID, WIFI_PASSWORD);
    Serial.printf("[NET] '%s' agina baglaniliyor", WIFI_SSID);

    const uint32_t t0 = millis();
    while (WiFi.status() != WL_CONNECTED && millis() - t0 < WIFI_TIMEOUT_MS)
    {
        delay(250);
        Serial.print('.');
    }
    Serial.println();

    if (WiFi.status() == WL_CONNECTED)
    {
        Serial.printf("[NET] Baglandi. IP: %s\n", WiFi.localIP().toString().c_str());
    }
    else
    {
        // Ag yoksa kendi erisim noktasini ac; robot her kosulda kontrol edilebilsin.
        WiFi.mode(WIFI_AP);
        WiFi.softAP(AP_SSID, AP_PASSWORD);
        Serial.printf("[NET] Ag bulunamadi. AP acildi: %s / %s  IP: %s\n",
                      AP_SSID, AP_PASSWORD, WiFi.softAPIP().toString().c_str());
    }

    if (MDNS.begin(MDNS_HOST))
    {
        MDNS.addService("http", "tcp", 80);
        Serial.printf("[NET] http://%s.local\n", MDNS_HOST);
    }
}

// ===========================================================================
void setup()
{
    Serial.begin(115200);
    delay(200);
    g_resetReason = resetReasonCode();
    Serial.printf("\n\n=== %s v%s ===\n", FW_NAME, FW_VERSION);
    Serial.printf("[SYS] Onceki reset sebebi: %s\n", resetReasonText());
    if (esp_reset_reason() == ESP_RST_BROWNOUT)
        Serial.println("[SYS] !! Besleme cokuyor. Servolara AYRI 5-6V kaynak ver, "
                       "GND'leri birlestir, servo hattina 1000uF kondansator koy.");

    // Once kol: cikislar kapali baslasin, servolar serbest kalsin.
    arm.begin();

    startNetwork();

    ws.onEvent(onWsEvent);
    server.addHandler(&ws);

    server.on("/", HTTP_GET, [](AsyncWebServerRequest *req)
              {
        // Sayfa dogrudan flash'tan akitilir; ~20 KB'lik heap kopyasi olusmaz.
        AsyncWebServerResponse *res = req->beginResponse(
            200, "text/html", (const uint8_t *)INDEX_HTML, strlen_P(INDEX_HTML));
        res->addHeader("Cache-Control", "no-store");
        req->send(res); });

    server.on("/favicon.ico", HTTP_GET, [](AsyncWebServerRequest *req)
              { req->send(204); });

    server.onNotFound([](AsyncWebServerRequest *req)
                      { req->redirect("/"); });

    server.begin();
    Serial.println("[WEB] Sunucu ayakta.");

    // Yigin: profil matematigi + NVS yazimi + Serial.printf icin rahat pay.
    xTaskCreatePinnedToCore(motionTask, "motion", 6144, nullptr, 3, nullptr, 1);
    Serial.println("[SYS] Hareket gorevi baslatildi (core 1, 100 Hz).");
    Serial.println("[SYS] Servolar SERBEST. Arayuzden ETKINLESTIR ile devreye al.");
}

void loop()
{
    static uint32_t lastTelemetry = 0;
    static uint32_t lastCleanup = 0;
    const uint32_t now = millis();

    if (now - lastCleanup >= 1000)
    {
        lastCleanup = now;
        ws.cleanupClients();
    }

    if (g_calChanged)
    {
        g_calChanged = false;
        if (ws.count())
            ws.textAll(buildCal());
    }

    if (now - lastTelemetry >= (1000 / TELEMETRY_HZ))
    {
        lastTelemetry = now;
        if (ws.count() && ws.availableForWriteAll())
        {
            char buf[256];
            const size_t n = buildState(buf, sizeof(buf));
            if (n > 0 && n < sizeof(buf))
                ws.textAll(buf, n);
        }
    }

    delay(2);
}

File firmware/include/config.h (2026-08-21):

/**
 * ArmPilot - Yapilandirma
 * ---------------------------------------------------------------------------
 * Robotla ilgili TUM ayarlanabilir degerler burada. Arayuz (web) bu dosyadaki
 * geometri/limit bilgilerini baglanti aninda ESP32'den okur; yani mekanik bir
 * degisiklikte SADECE bu dosyayi duzenlemen yeterli.
 */
#pragma once

#include <Arduino.h>

// ============================ KIMLIK =======================================
#define FW_NAME "ArmPilot"
#define FW_VERSION "2.1.0"

// ============================ AG AYARLARI ==================================
// WiFi bilgileri surum kontrolune GIRMEZ. include/secrets_example.h dosyasini
// include/secrets.h olarak kopyalayip kendi aginin bilgilerini gir.
// secrets.h yoksa ornek dosya kullanilir ve derlemede uyari verilir.
#if __has_include("secrets.h")
#include "secrets.h"
#else
#include "secrets_example.h"
#warning "include/secrets.h bulunamadi -> secrets_example.h kullaniliyor. Kopyalayip WiFi bilgilerini gir."
#endif

#define WIFI_TIMEOUT_MS 15000 // Bu surede baglanamazsa kendi AP'sini acar
#define AP_SSID "ArmPilot-AP"
#define AP_PASSWORD "armpilot1" // En az 8 karakter olmali
#define MDNS_HOST "armpilot"    // http://armpilot.local

// ============================ DONANIM ======================================
#define PCA9685_ADDR 0x40
#define I2C_SDA_PIN 21
#define I2C_SCL_PIN 22
#define I2C_CLOCK_HZ 400000
#define SERVO_FREQ_HZ 50
#define OSCILLATOR_FREQ 25000000UL

// PCA9685 /OE pini. Bagliysa GPIO numarasini yaz (HIGH = tum cikislar kapali).
// Bagli degilse -1 birak; yazilim kanallari "full-off" yaparak ayni isi gorur.
#define PCA9685_OE_PIN -1

// ============================ KONTROL DONGUSU ==============================
#define CTRL_HZ 100             // Hareket profili guncelleme frekansi
#define TELEMETRY_HZ 20         // Arayuze durum yayini
#define ENGAGE_STAGGER_MS 220   // Servolari tek tek devreye alma araligi (akim piki icin)
#define IDLE_SAVE_DELAY_MS 2000 // Hareket bittikten sonra pozu NVS'e yazma gecikmesi
#define MIN_SAVE_INTERVAL_MS 8000

// ============================ EKSENLER =====================================
#define NUM_JOINTS 5

enum JointId : uint8_t
{
    J_BASE = 0,     // Taban donusu (yaw)
    J_SHOULDER = 1, // Omuz
    J_ELBOW = 2,    // Dirsek
    J_WRIST = 3,    // Bilek (pitch)
    J_GRIPPER = 4   // Kiskac
};

/**
 * Tek bir eksenin tum tanimi.
 *  minDeg/maxDeg : yazilimsal guvenlik limitleri (mekanik carpismayi onler)
 *  maxVel        : deg/s   - ust hiz siniri
 *  maxAcc        : deg/s^2 - ivme siniri (yumusak kalkis/durus)
 *  maxJerk       : deg/s^3 - ivme degisim siniri (S-egrisi hissi)
 *  usMin/usMax   : bu servonun 0 ve 180 derecedeki darbe genisligi (kalibrasyon)
 *  invert        : servo ters monteliyse -1 yap (arayuz hep 0..180 mantigi gorur)
 */
struct JointConfig
{
    const char *name;
    uint8_t channel;
    float minDeg;
    float maxDeg;
    float homeDeg;
    float parkDeg;
    float maxVel;
    float maxAcc;
    float maxJerk;
    uint16_t usMin;
    uint16_t usMax;
    int8_t invert;
};

extern const JointConfig JOINTS[NUM_JOINTS];

// ============================ GEOMETRI (mm) ================================
// Arayuzdeki kolun sekli bu olculere gore cizilir. Gercek olculerini gir.
struct ArmGeometry
{
    float baseRadius;   // Taban silindirinin yaricapi (gorsel)
    float baseHeight;   // Zeminden omuz eksenine yukseklik
    float linkUpperArm; // Omuz -> Dirsek
    float linkForearm;  // Dirsek -> Bilek
    float linkGripper;  // Bilek -> Kiskac ucu
};

extern const ArmGeometry GEOMETRY;

// ============================ KALIBRASYON ==================================
// Servo hornlari montajda rastgele bir acida takildigi icin "servo 0 = kol
// duz" gibi bir varsayim yapilamaz. Her eklem icin servo acisi ile eklemin
// gercek acisi arasinda DOGRUSAL bir bagintI kurulur:
//
//   eklem_acisi = wRef + gain * (servo_acisi - sRef)
//
//   sRef : ornek alinan noktadaki servo acisi
//   wRef : ayni noktada eklemin gercek acisi
//   gain : eklem acisi / servo acisi. Isareti YONU (ters monte = negatif),
//          buyuklugu ise varsa disli/kayis ORANINI tasir. Dogrudan tahrikli
//          bir eklemde +1 veya -1 cikar.
//
// "eklem_acisi" ne demek:
//   omuz   -> ust kolun DUNYA acisi (90 = dimdik yukari)
//   dirsek -> seri kinematikte bir onceki uzva GORE aci (0 = uzuvlar ayni
//             dogrultuda), paralel kinematikte dunyada 90'dan sapma
//   bilek  -> ayni mantik
//
// Iki bilinmeyen (sRef/wRef ikilisi ve gain) oldugu icin cozum ICIN IKI ORNEK
// gerekir: arayuzdeki KALIBRASYON MODU'nda kullanici ekrandaki kolu gercek
// kola benzetip iki farkli pozda "nokta kaydet" der, firmware gain'i ve
// referansi bu iki noktadan cozer. Sonuc NVS'e yazilir; asagidakiler sadece
// ilk acilis / fabrika ayari degerleridir.
struct JointCal
{
    float sRef;
    float wRef;
    float gain;
};

extern const JointCal CAL_DEFAULT[3]; // omuz, dirsek, bilek
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

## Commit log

2026-04-27 Revise README for ESP32 5-DOF Manipulator
    Updated the README to provide detailed information about the ESP32 5-DOF manipulator, including technical implementation, hardware setup, and upcoming work.
2026-04-27 Add initial firmware and documentation for ESP32 Robot Arm Controller
    - Added multiple PNG images for the XL4015 DC-DC step-down converter.
    - Included circuit diagram files in Fritzing format.
    - Added imports for various electronic components including battery holder and servo breakout.
    - Introduced main firmware code for controlling servos using PCA9685.
    - Implemented a web interface for real-time control of the robot arm.
    - Added README files for project structure and header file usage.
    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
    [18650_holder+v8.f3z, Arm.stl, Assembly.f3z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]
2026-04-27 Update README with physical prototype details and add full assembly image
2026-04-28 Update README and add electronics schematics and components
    [Circuit Diagram.fzz]
2026-04-28 docs: add circuit diagram image to hardware setup section in README
2026-04-28 fix: update Assembly.png in CAD directory
2026-04-28 fix: correct file name for circuit diagram in hardware setup section of README
2026-04-28 fix: update circuit diagram file name and add new files for electronics
    [Circuit_Diagram.fzz]
2026-04-28 fix: correct image path for circuit diagram in README
2026-08-21 Add README for PlatformIO Test Runner and Unit Testing information
    [Assembly.f3z, Axis 1 Lid.stl, Axis 1 Servo Cover.stl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]
2026-08-22 readme updated and circuit diagram added
2026-09-03 Fix circuit diagram filename case
